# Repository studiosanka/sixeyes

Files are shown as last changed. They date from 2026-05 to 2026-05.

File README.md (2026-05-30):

# SixEyes - 6-DOF Robotic Arm with ROS2 Integration

An open-source, in-progress robotics platform for a 6-degree-of-freedom arm, spanning ESP32 firmware, ROS2 integration, teleoperation tooling, and hardware bring-up.

NodeMesh-specific firmware and IC-design work has moved to a dedicated repository: [https://github.com/SixEyes-Open-Source/nodemesh](https://github.com/SixEyes-Open-Source/nodemesh).

## Scope Clarity (Read This First)

SixEyes is the standard robotic-arm package.

- Standard path in this repository: arm hardware + follower/leader firmware + laptop/ROS2-assisted operation.
- Optional path in NodeMesh repository: 4-MCU edge firmware system with camera nodes and ESP-NOW.

Important default policy for this repository:
- SD card reader hardware may be present as a compatibility option, but it is not part of the default sixeyes runtime flow.
- ESP32-CAM perception nodes are not part of the standard sixeyes package.

Canonical split across all repos:
- [Project Scope And Repo Map](docs/PROJECT_SCOPE_AND_REPO_MAP.md)

## Quick Links

- 📘 **Getting Started**: Read [Complete Documentation Index](docs/README.md#quick-start)
- 🧠 **NodeMesh Repository**: [SixEyes-Open-Source/nodemesh](https://github.com/SixEyes-Open-Source/nodemesh)
- 🚀 **Deploy Firmware**: [Flashing & Deployment Guide](docs/deployment/FLASHING_AND_DEPLOYMENT.md)
- 🔌 **Build Hardware**: [Wiring & Assembly Guide](docs/hardware/WIRING_AND_ASSEMBLY.md)
- 🧩 **Pinout Matrix**: [Dual-Controller Pinout & Wiring Matrix](docs/hardware/DUAL_CONTROLLER_PINOUT_MATRIX.md)
-  **System Architecture**: [Visual Architecture Guide](docs/firmware/VISUAL_ARCHITECTURE_GUIDE.md)
- 🎮 **Teleoperation Architecture**: [Dual-Mode Firmware Plan](docs/firmware/TELEOPERATION_MODE_ARCHITECTURE.md)
- ✅ **Validate Hardware**: [Hardware Validation Procedures](docs/hardware/HARDWARE_VALIDATION.md)
- 🛠️ **Run Tests**: [Testing & Validation Guide](docs/testing/TESTING_AND_VALIDATION_GUIDE.md)

## Project Overview

### System Architecture

```
┌─────────────────────────────────┐
│  ROS2 Safety Node (Laptop)      │
│  • Heartbeat control (50 Hz)    │
│  • Motion planning              │
│  • Emergency stop logic         │
└──────────────┬──────────────────┘
               │ USB-CDC (ASCII)
┌──────────────▼──────────────────┐
│  ESP32-S3 Follower (Embedded)   │
│  • 500 Hz control loop          │
│  • Motor drivers (TMC2209)      │
│  • Servo control (LEDC PWM)     │
│  • Safety monitoring            │
└──────────────┬──────────────────┘
               │ Power + Control
┌──────────────▼──────────────────┐
│  Hardware (SixEyes Robot)       │
│  • 4× NEMA23 steppers (24V)     │
│  • 3× MG996R servos (6.6V rail) │
│  • USB-CDC telemetry            │
└─────────────────────────────────┘
```

### Key Features

✅ **Safety-Critical**: Dual heartbeat monitoring with <2.5 ms motor disable latency  
✅ **Real-Time Control**: 500 Hz FreeRTOS deterministic control loop  
✅ **Extensible**: JSON message protocol for future expansion  
🚧 **In Active Development**: Architecture and workflows are evolving as teleoperation and ROS2 integration mature  
✅ **Well-Tested**: Unit tests + hardware validation procedures  
✅ **CI/CD Ready**: GitHub Actions for automated builds and releases  

### Firmware Operation Modes

| Mode | Purpose | Data Path | Status |
|---|---|---|---|
| **VLA Inference** | Execute AI-planned tasks from laptop/ROS2 | Laptop ROS2 → Follower ESP32 | ✅ Active |
| **Teleoperation** | Stream human-driven leader joint states for mirroring/data collection | Leader ESP32 → Laptop → Follower | ✅ Fully wired (hardware pending) |

Current implementation includes `leader_esp32` JOINT_STATE streaming at 100 Hz, laptop bridge forwarding, teleoperation command handling on follower, and operator utilities for safe command sequencing.

### Choose Your Mode First (Important)

Before building/flashing, choose one workflow and set follower mode accordingly:

1. **VLA Inference workflow**
    - Set in `firmware/follower_esp32/platformio.ini`:
       ```ini
       -DOPERATION_MODE=1
       ```
    - Flash only `follower_esp32`
    - Run ROS2 safety + command nodes from laptop

2. **Teleoperation workflow**
    - Set in `firmware/follower_esp32/platformio.ini`:
       ```ini
       -DOPERATION_MODE=2
       ```
    - Flash both `leader_esp32` and `follower_esp32`
    - Run laptop bridge (`tools/teleoperation_bridge.py`)

## Repository Structure

```
firmware/
├── follower_esp32/              ← Main firmware
│   ├── src/
│   │   ├── main.cpp             (entry point)
│   │   ├── modules/
│   │   │   ├── motor_control/   (500 Hz PID control loop)
│   │   │   ├── servo_control/   (LEDC PWM servo manager)
│   │   │   ├── safety/          (heartbeat, fault manager, safety task)
│   │   │   ├── comms/           (USB-CDC, JSON parser, message router)
│   │   │   ├── modes/           (vla_inference, teleoperation handlers)
│   │   │   ├── drivers/         (TMC2209, LEDC)
│   │   │   └── hal/             (GPIO, timekeeping)
│   │   └── config/              (board_config.h, mode_config.h)
│   ├── test/                    (unit tests & mocks)
│   ├── platformio.ini           (build config)
│   └── lib_deps                 (dependencies)
└── leader_esp32/                (teleoperation joint-state streamer, 100 Hz)

ros2_ws/                         ← ROS2 workspace (runs on laptop)
├── src/
│   ├── safety_node/             ✅ Monitors firmware status, publishes /sixeyes/is_safe
│   ├── vla_inference_node/      🚧 VLA inference stub (in development)
│   ├── camera_node/             ✅ OpenCV camera → /camera/image_raw
│   ├── joint_state_node/        ✅ Bridges /sixeyes/joint_states → /joint_states (rad)
│   └── usb_bridge_node/         ✅ Owns serial port; heartbeat TX, telemetry RX, command TX

simulation/                      ← Gazebo simulation
├── models/
└── launch/

hardware_assets/                 ← Mechanical + PCB production files
├── 3d_print_stl/                (STL files for printed parts)
└── pcb_schematic_gerber/        (schematics + Gerbers)

SixEyes Follower PCB/            ← KiCad PCB project (follower controller board)
├── SixEyes Follower PCB.kicad_pcb
├── SixEyes Follower PCB.kicad_sch
├── SixEyes Follower PCB.kicad_pro
├── SixEyes_Custom.pretty/       (custom footprint library)
└── design_inputs/               (netlists, footprint maps)

docs/                            ← Documentation ⭐ START HERE
├── README.md                    (doc navigation)
├── firmware/                    (implementation guides)
├── hardware/                    (wiring & assembly)
├── deployment/                  (flashing guide)
├── testing/                     (validation procedures)
├── protocols/                   (message specs)
├── ros2/                        (ROS2 integration)
├── ops/                         (CI/CD pipeline)
└── references/                  (datasheets, etc)

.github/workflows/               ← CI/CD pipelines
├── platformio-build.yml
├── code-quality.yml
└── release.yml

CONTRIBUTING.md                  (contribution guidelines)
LICENSE                          (project license)
README.md                        (this file)
```

## Getting Started (5 minutes)

### Quick Mode Setup

```bash
# Follower mode switch (edit before build)
cd firmware/follower_esp32
# platformio.ini -> -DOPERATION_MODE=1  (VLA)
# platformio.ini -> -DOPERATION_MODE=2  (Teleoperation)
```

### For Firmware Developers

1. **Clone the repository**:
   ```bash
   git clone https://github.com/SixEyes-Open-Source/sixeyes.git
   ```
   All code is at the repository root — `firmware/`, `ros2_ws/`, `tools/` etc. are top-level folders.

2. **Install PlatformIO**:
   ```bash
   pip install platformio
   cd firmware/follower_esp32
   ```

3. **Build firmware**:
   ```bash
   pio run
   ```

4. **Flash to ESP32**:
   ```bash
   pio run -t upload
   ```

5. **Monitor output**:
   ```bash
   pio device monitor
   ```

⏭️ **Next**: Read [Flashing & Deployment Guide](docs/deployment/FLASHING_AND_DEPLOYMENT.md)

### For Teleoperation Mode (Phase 2)

1. **Build leader streamer firmware**:
   ```bash
   cd firmware/leader_esp32
   pio run
   ```

2. **Build follower in teleoperation mode**:
   ```bash
   cd ../follower_esp32
   # Ensure platformio.ini has: -DOPERATION_MODE=2
   pio run
   ```

3. **Flash leader ESP32**:
   ```bash
   cd ../leader_esp32
   pio run -t upload
   ```

4. **Flash follower ESP32**:
   ```bash
   cd ../follower_esp32
   pio run -t upload
   ```

5. **Monitor JOINT_STATE output (100 Hz)**:
   ```bash
   cd ../leader_esp32
   pio device monitor
   ```

6. **Capture leader pot home pose as zero (in leader monitor)**:
   ```text
   HOME_ZERO
   ```
   Or JSON form:
   ```json
   {"cmd":"CAPTURE_ZERO"}
   ```
   Expected monitor response:
   ```text
   [CAL] Leader pot zero captured from current pose
   ```

7. **Run laptop bridge with dataset capture**:
   ```bash
   cd tools
   python teleoperation_bridge.py --leader-port COM5 --follower-port COM6 --log-file logs/teleop_session.jsonl
   ```

8. **Validate captured JSONL against schema**:
   ```bash
   cd tools
   python validate_teleop_log.py --input logs/teleop_session.jsonl
   ```

9. **Run operator workflow helper (optional, follower commands + heartbeat)**:
   ```bash
   cd tools
   python operator_control.py --port COM6 teleop-ready
   python operator_control.py --port COM6 home
   python operator_control.py --port COM6 stallguard-home
   ```

⏭️ **Next**: Read [Teleoperation Mode Architecture](docs/firmware/TELEOPERATION_MODE_ARCHITECTURE.md)

### For Hardware Assembly

1. **Gather components** from [Parts List](docs/hardware/WIRING_AND_ASSEMBLY.md#parts-list)
2. **Follow wiring diagram** in [Wiring Guide](docs/hardware/WIRING_AND_ASSEMBLY.md)
3. **Run hardware validation** tests from [Hardware Validation](docs/hardware/HARDWARE_VALIDATION.md)

⏭️ **Next**: Read [WIRING_AND_ASSEMBLY.md](docs/hardware/WIRING_AND_ASSEMBLY.md)

### For ROS2 Integration

1. **Set up ROS2 workspace**:
   ```bash
   cd ros2_ws
   colcon build
   source install/setup.bash
   ```

2. **Run all nodes** with a single launch command:
   ```bash
   # Teleoperation mode (4 nodes)
   ros2 launch sixeyes_bringup teleop.launch.py port:=/dev/ttyACM0

   # VLA inference mode (5 nodes, includes vla_inference_node stub)
   ros2 launch sixeyes_bringup vla.launch.py port:=/dev/ttyACM0
   ```

3. **Monitor firmware status**:
   ```bash
   ros2 topic echo /sixeyes/firmware_status
   ros2 topic echo /sixeyes/is_safe
   ```

⏭️ **Next**: Read [ROS2 Integration Guide](docs/ros2/ROS2_HEARTBEAT_INTEGRATION.md)

## Technical Specifications

| Feature | Specification |
|---|---|
| **Controller** | ESP32-S3 (240 MHz dual-core, 320 KB RAM) |
| **Control Loop** | 500 Hz FreeRTOS deterministic timing |
| **Steppers** | 4× NEMA23 (24V, 2.8A nominal) via TMC2209 |
| **Servos** | 3× MG996R (6.6V rail, 0.17 sec/60°) |
| **Communication** | USB-CDC + heartbeat protocol (50+ Hz) |
| **Safety Timeout** | 500 ms heartbeat detection + <2.5 ms motor disable |
| **Memory Usage** | 6.1% RAM, 10% Flash |
| **Build Status** | Zero compiler warnings ✅ |

## Key Documentation Files

### 📚 Architecture & Design
- [Visual Architecture Guide](docs/firmware/VISUAL_ARCHITECTURE_GUIDE.md) - System diagrams, control flow, timing diagrams
- [Implementation Summary](docs/firmware/IMPLEMENTATION_SUMMARY.md) - Technical specifications, protocol details

### 🔧 Hardware & Deployment
- [Wiring & Assembly](docs/hardware/WIRING_AND_ASSEMBLY.md) - Complete pin mapping, parts list, assembly procedures
- [Hardware Validation](docs/hardware/HARDWARE_VALIDATION.md) - Testing & qualification procedures
- [Flashing & Deployment](docs/deployment/FLASHING_AND_DEPLOYMENT.md) - Firmware build, flash, troubleshooting

### 🧪 Testing & Quality
- [Testing & Validation Guide](docs/testing/TESTING_AND_VALIDATION_GUIDE.md) - Unit tests, test framework, coverage
- [CI/CD Pipeline](docs/ops/CI_CD_PIPELINE.md) - GitHub Actions, automated builds, release process

### 🚀 Communication & ROS2
- [JSON Message Protocol](docs/protocols/JSON_MESSAGE_PROTOCOL.md) - Message specifications, command reference
- [ROS2 Heartbeat Integration](docs/ros2/ROS2_HEARTBEAT_INTEGRATION.md) - Safety protocol, integration details
- [ROS2 Quickstart](docs/ros2/ROS2_HEARTBEAT_QUICKSTART.md) - Step-by-step testing guide

### 📋 References
- [Datasheets & References](docs/references/) - TMC2209, hardware specs, technical references
- [Firmware System Datasheet](docs/references/FIRMWARE_SYSTEM_DATASHEET.md) - IC-style firmware system snapshot (interfaces, safety, limits, maturity)

## Communication Protocols

### ASCII Heartbeat (High-Priority Safety)

**ROS2 → ESP32** (≥50 Hz):
```
HB:0,<sequence>\n
```

**ESP32 → ROS2** (10 Hz):
```
SB:<fault>,<motors_enabled>,<ros2_alive>\n
```

### JSON Message Protocol (Extensible Commands)

```json
{
  "cmd": "MOTOR_TARGET",
  "seq": 1,
  "targets": [0.0, 45.0, 90.0, 135.0]
}
```

See [JSON Message Protocol](docs/protocols/JSON_MESSAGE_PROTOCOL.md) for full specification.

## Safety & Reliability

### Motor Disable Guarantees

- **Automatic Disable**: If ROS2 heartbeat lost for >500 ms
- **Latency**: Motor disable within 1 control loop cycle (~2.5 ms)
- **Dual Monitoring**: Both ROS2 and internal heartbeat must be healthy
- **Non-blocking**: All safety checks run asynchronously to preserve control loop timing

### Testing & Validation

✅ 17 unit tests (all passing)  
✅ 15 hardware validation procedures  
✅ CI/CD automated builds with memory constraints  
⚠️ Some non-blocking ArduinoJson deprecation warnings remain  
✅ Build-ready code quality (leader + follower compile successfully)  

## Development Workflow

### Building Locally

```bash
cd firmware/follower_esp32
pio run              # Build
pio run -t upload    # Flash
pio device monitor   # Monitor
```

### Running Unit Tests

```bash
cd firmware/follower_esp32
pio test             # Run all tests
```

### Contributing

See [CONTRIBUTING.md](CONTRIBUTING.md) for:
- Code style guidelines
- Pull request process
- Commit message conventions
- Testing requirements

## Troubleshooting

### Compilation Issues
👉 See [Build Troubleshooting](docs/deployment/FLASHING_AND_DEPLOYMENT.md#troubleshooting)

### Hardware Not Responding
👉 See [Hardware Validation](docs/hardware/HARDWARE_VALIDATION.md#troubleshooting)

### ROS2 Communication Problems
👉 See [ROS2 Quickstart - Troubleshooting](docs/ros2/ROS2_HEARTBEAT_QUICKSTART.md#troubleshooting)

## Project Status

| Component | Status | Notes |
|---|---|---|
| Firmware Core (VLA) | ✅ Stable | Follower control loop + safety heartbeat |
| Firmware Core (Teleop) | ✅ Active | Leader stream + bridge + follower telemetry + schema-validated logging |
| Documentation | ✅ Active | Dual-mode docs updated; ongoing refinements |
| Unit Tests | 🟡 Partial | Existing tests pass; teleop path tests still needed |
| CI/CD Pipeline | ✅ Complete | 3 GitHub Actions workflows |
| Hardware Validation | ✅ Available | Baseline + teleoperation checks documented |
| ROS2 Integration | 🟡 Partial | Heartbeat path done; teleop ROS nodes need expansion |
| Production Readiness | 🚧 In Progress | Core safety + control are advancing; end-to-end teleop and ROS2 workflows are still being completed |

## Current TODO (High Priority)

1. Add automated integration test for `leader_esp32` → bridge → `follower_esp32`
2. Expand ROS2 workspace teleoperation nodes (`joint_state_node`, `usb_bridge_node`) for end-to-end runtime
3. Finalize hardware bring-up checklist for dual-controller (leader + follower) setups

## Performance Metrics

```
Control Loop Frequency:      400 Hz ✓
Motor Disable Latency:       < 2.5 ms ✓
Firmware Size:               335 KB ✓
RAM Usage:                   6.1% ✓
Flash Usage:                 10% ✓
Compiler Warnings:           0 ✓
Unit Test Coverage:          17 tests passing ✓
```

## License

This project is licensed under the [LICENSE](LICENSE) file.

## Contact & Support

For issues, questions, or contributions:
- 📧 Email: sixeyesopensource@gmail.com
- 🐛 Issues: https://github.com/SixEyes-Open-Source/sixeyes/issues
- 💬 Discussions: https://github.com/SixEyes-Open-Source/sixeyes/discussions

---

**Last Updated**: March 2026  
**Latest Version**: Check [Releases](https://github.com/SixEyes-Open-Source/sixeyes/releases)

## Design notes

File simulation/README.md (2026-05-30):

# Simulation

Place simulators and models here. Simulation-first development is required. Use this folder for Gazebo/ignition or pybullet scenes that mimic the real robot and its power/safety constraints.

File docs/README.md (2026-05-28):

# SixEyes Documentation Index

Navigation guide for SixEyes firmware, ROS2, teleoperation, and hardware documentation.

NodeMesh-specific materials now live in a separate repository: [https://github.com/SixEyes-Open-Source/nodemesh](https://github.com/SixEyes-Open-Source/nodemesh).

## Scope Boundary (Critical)

- This docs tree is for standard sixeyes hardware and firmware workflows.
- NodeMesh is optional and maintained in a separate repository.
- If you are doing the default build, you do not need NodeMesh docs.

See authoritative boundaries here:
- [Project Scope And Repo Map](PROJECT_SCOPE_AND_REPO_MAP.md)

## Minimal Start Path (3 Docs Only)

If you feel overwhelmed, start with only these:

1. [Wiring & Assembly](hardware/WIRING_AND_ASSEMBLY.md)
2. [Flashing & Deployment](deployment/FLASHING_AND_DEPLOYMENT.md)
3. [Hardware Validation](hardware/HARDWARE_VALIDATION.md)

Then expand to other docs only as needed.

## Quick Start

👉 **New to SixEyes?** Start here based on your role:

### 🧑‍💻 Firmware Developers
1. Read: [Implementation Summary](firmware/IMPLEMENTATION_SUMMARY.md) (5 min)
2. Read: [Visual Architecture Guide](firmware/VISUAL_ARCHITECTURE_GUIDE.md) (10 min)
3. Read: [Teleoperation Mode Architecture](firmware/TELEOPERATION_MODE_ARCHITECTURE.md) (dual-mode design)
4. Follow: [Flashing & Deployment](deployment/FLASHING_AND_DEPLOYMENT.md) to build firmware
5. Run: [Unit Tests](testing/TESTING_AND_VALIDATION_GUIDE.md) to verify code

### 🎮 Teleoperation Developers
1. Read: [Teleoperation Mode Architecture](firmware/TELEOPERATION_MODE_ARCHITECTURE.md)
2. Reference: [JSON Message Protocol](protocols/JSON_MESSAGE_PROTOCOL.md#teleoperation-streaming-messages-phase-2)
3. Build: `sixeyes/firmware/leader_esp32` (joint-state streamer)
4. Run bridge: `python sixeyes/tools/teleoperation_bridge.py --leader-port COM5 --follower-port COM6`
5. Validate: `JOINT_STATE` forwarding + optional JSONL logging
6. Optional: run `python sixeyes/tools/operator_control.py --port COM6 teleop-ready` for follower-side safety/enable command flow

### 🔧 Hardware Integrators
1. Gather: [Parts List](hardware/WIRING_AND_ASSEMBLY.md#parts-list)
2. Follow: [Wiring & Assembly](hardware/WIRING_AND_ASSEMBLY.md) step-by-step
3. Run: [Hardware Validation Tests](hardware/HARDWARE_VALIDATION.md) to verify setup
4. Deploy: [Flashing Guide](deployment/FLASHING_AND_DEPLOYMENT.md) to install firmware

### 🤖 ROS2 Engineers
1. Read: [ROS2 Heartbeat Integration](ros2/ROS2_HEARTBEAT_INTEGRATION.md) (understand protocol)
2. Follow: [ROS2 Quickstart](ros2/ROS2_HEARTBEAT_QUICKSTART.md) for testing
3. Reference: [JSON Message Protocol](protocols/JSON_MESSAGE_PROTOCOL.md) for commands
4. Check: [CI/CD Pipeline](ops/CI_CD_PIPELINE.md) for build automation

### 🚀 DevOps / Release Engineers
1. Read: [CI/CD Pipeline Documentation](ops/CI_CD_PIPELINE.md)
2. Review: [Flashing & Deployment](deployment/FLASHING_AND_DEPLOYMENT.md#release--version-management)
3. Check: [GitHub Workflows](.github/workflows/) for automation details

---

## Documentation by Category

### 📘 Firmware Architecture & Design

#### [Implementation Summary](firmware/IMPLEMENTATION_SUMMARY.md)
- **Contents**: ROS2 heartbeat protocol, module specifications, compilation results
- **Best For**: Understanding core firmware architecture, protocol details
- **Read Time**: 20 minutes
- **Key Sections**:
  - Bidirectional heartbeat protocol (HB: and SB: packets)
  - Four firmware modules (HeartbeatReceiver, SafetyBridge, HeartbeatTransmitter, SafetyNodeBridge)
  - SafetyTask integration with ROS2 hooks
  - Performance metrics (6.1% RAM, 10% Flash)

#### [Visual Architecture Guide](firmware/VISUAL_ARCHITECTURE_GUIDE.md)
- **Contents**: System diagrams, control flow, timing analysis, pin mapping
- **Best For**: Visual learners, understanding data flow, timing guarantees
- **Read Time**: 15 minutes
- **Key Sections**:
  - High-level system architecture diagram
  - 400 Hz control loop timeline (2.5 ms per cycle breakdown)
  - Module dependency graph
  - Hardware pin mapping and configuration
  - Signal flow diagrams

#### [Teleoperation Mode Architecture](firmware/TELEOPERATION_MODE_ARCHITECTURE.md)
- **Contents**: Dual-mode firmware plan, teleoperation protocol, module roadmap
- **Best For**: Implementing leader-follower mirroring and data-collection flow
- **Read Time**: 15 minutes
- **Key Sections**:
  - VLA Inference vs Teleoperation mode comparison
  - `JOINT_STATE` and `TELEMETRY_STATE` data-flow design
  - Phase-based implementation plan (Phase 1 → Phase 3)

---

### 🔌 Hardware & Assembly

#### [Wiring & Assembly](hardware/WIRING_AND_ASSEMBLY.md)
- **Contents**: Parts list, pinout reference, power distribution, motor/servo wiring
- **Best For**: Physical hardware assembly, electrical integration
- **Read Time**: 30 minutes
- **Key Sections**:
  - Complete parts list with part numbers
  - ESP32-S3 pin assignments (all pins documented)
  - TMC2209 stepper driver wiring
  - Servo motor connections (LEDC PWM)
  - Power distribution strategy (star grounding)
  - Grounding and noise management

#### [Dual-Controller Pinout & Wiring Matrix](hardware/DUAL_CONTROLLER_PINOUT_MATRIX.md)
- **Contents**: Consolidated pin map for leader ESP32-C6 SuperMini and follower ESP32-S3, 4× TMC2209 channels, servos, UART links, and power rails
- **Best For**: Fast verification of inter-board wiring and GPIO assignments against Technical Reference 2
- **Read Time**: 8 minutes
- **Key Sections**:
  - Leader ADC and UART pin mapping
  - Follower TMC2209 + servo pin mapping
  - Inter-board UART cross-link table
  - Power rail distribution and grounding rules

#### [Hardware Validation](hardware/HARDWARE_VALIDATION.md)
- **Contents**: Testing procedures, validation checklists, troubleshooting
- **Best For**: Verifying hardware is correctly assembled
- **Read Time**: 20 minutes (execution time ~2 hours for full validation)
- **Key Sections**:
  - Pre-testing checklists (power, connections, firmware)
  - Unit-level tests (power-on, GPIO blink, UART loopback)
  - Integration tests (motor enable/disable, heartbeat timeout, servo response)
  - System-level tests (load testing, stress testing)
  - Failure mode testing and recovery

---

### 🚀 Firmware Deployment

#### [Flashing & Deployment](deployment/FLASHING_AND_DEPLOYMENT.md)
- **Contents**: Build instructions, flashing methods, diagnostics, troubleshooting
- **Best For**: Compiling and installing firmware on ESP32
- **Read Time**: 25 minutes (execution time ~10 minutes per flash)
- **Key Sections**:
  - Pre-deployment checklist (tools, hardware prep, prerequisites)
  - Firmware build with PlatformIO (CLI and VS Code)
  - Multiple flashing methods (USB in DFU mode, UART serial)
  - Serial monitor diagnostics and startup verification
  - Troubleshooting common build and flash errors
  - Release and version management

---

### 🧪 Testing & Quality Assurance

#### [Testing & Validation Guide](testing/TESTING_AND_VALIDATION_GUIDE.md)
- **Contents**: Unit test framework, running tests, coverage, simulation
- **Best For**: Developers writing and running unit tests
- **Read Time**: 20 minutes
- **Key Sections**:
  - Unit test framework architecture (mock hardware objects)
  - MockSerial, MockGPIO, MockTimer, MockFreeRTOS
  - Running tests on desktop (no ESP32 required)
  - Test coverage analysis (heartbeat parsing, safety logic, motor control)
  - Simulation harness for non-blocking operations
  - CI/CD integration with GitHub Actions

---

### 🛠️ Communication Protocols

#### [JSON Message Protocol](protocols/JSON_MESSAGE_PROTOCOL.md)
- **Contents**: Message format, command types, response types, error handling
- **Best For**: Building ROS2 nodes or custom applications
- **Read Time**: 25 minutes
- **Key Sections**:
  - Protocol overview (extensible, non-blocking, type-safe)
  - Message format with common fields (cmd, seq, ts)
  - Command and response message reference (implemented + planned)
  - Examples for each message type
  - Error handling and edge cases
  - Integration examples with Python/C++

---

### 🤖 ROS2 Integration

#### [ROS2 Heartbeat Integration](ros2/ROS2_HEARTBEAT_INTEGRATION.md)
- **Contents**: Heartbeat protocol, module breakdown, architecture, integration details
- **Best For**: Understanding heart beat safety mechanism
- **Read Time**: 20 minutes
- **Key Sections**:
  - Bidirectional heartbeat protocol (HB and SB packets)
  - Safety guarantees (dual heartbeat monitoring, <2.5 ms disable latency)
  - Module architecture (HeartbeatReceiver, Monitor, Transmitter)
  - Integration with SafetyTask and motor control
  - Timing and latency analysis

#### [ROS2 Quickstart Guide](ros2/ROS2_HEARTBEAT_QUICKSTART.md)
- **Contents**: Step-by-step testing, hardware setup, troubleshooting
- **Best For**: Quick hands-on testing of ROS2 integration
- **Read Time**: 15 minutes (testing ~30 minutes)
- **Key Sections**:
  - Quick verification test (2 minutes)
  - Full integration test (15 minutes)
  - Python node examples with diagnostics
  - Stress testing and failure injection
  - Common issues and solutions

---

### ⚙️ Operations & CI/CD

#### [CI/CD Pipeline](ops/CI_CD_PIPELINE.md)
- **Contents**: GitHub Actions workflows, build configuration, testing automation
- **Best For**: DevOps engineers, release automation
- **Read Time**: 20 minutes
- **Key Sections**:
  - Pipeline architecture overview
  - Build workflow (PlatformIO compilation, memory constraints)
  - Code quality workflow (static analysis, linting)
  - Release workflow (versioning, artifact generation)
  - Configuration customization
  - Troubleshooting build failures

---

### 📚 References & Resources

#### [References Directory](references/)
- **Contents**: Datasheets, technical specifications, hardware manuals
- **Best For**: Looking up chip specifications, pinouts, electrical specs
- **Files**:
  - `FIRMWARE_SYSTEM_DATASHEET.md` - Firmware-level system datasheet (interfaces, limits, safety behavior, maturity)
  - `SixEyes Technical Reference.txt` - Hardware technical specifications

---

## Documentation Map by Task

### Task: "I need to build the hardware"
1. Start: [Wiring & Assembly](hardware/WIRING_AND_ASSEMBLY.md)
2. Verify: [Hardware Validation](hardware/HARDWARE_VALIDATION.md)
3. Install: [Flashing & Deployment](deployment/FLASHING_AND_DEPLOYMENT.md)

### Task: "I need to understand how it works"
1. Start: [Implementation Summary](firmware/IMPLEMENTATION_SUMMARY.md)
2. Visualize: [Visual Architecture Guide](firmware/VISUAL_ARCHITECTURE_GUIDE.md)
3. Deep dive: [JSON Message Protocol](protocols/JSON_MESSAGE_PROTOCOL.md)

### Task: "I need to set up ROS2"
1. Start: [ROS2 Heartbeat Integration](ros2/ROS2_HEARTBEAT_INTEGRATION.md)
2. Test: [ROS2 Quickstart](ros2/ROS2_HEARTBEAT_QUICKSTART.md)
3. Command: [JSON Message Protocol](protocols/JSON_MESSAGE_PROTOCOL.md)

### Task: "I need to run the tests"
1. Start: [Testing & Validation Guide](testing/TESTING_AND_VALIDATION_GUIDE.md)
2. Hardware: [Hardware Validation](hardware/HARDWARE_VALIDATION.md)
3. CI/CD: [CI/CD Pipeline](ops/CI_CD_PIPELINE.md)

### Task: "I need to deploy a new version"
1. Start: [Flashing & Deployment](deployment/FLASHING_AND_DEPLOYMENT.md)
2. CI/CD: [CI/CD Pipeline](ops/CI_CD_PIPELINE.md)
3. Release: [Flashing Guide - Release Section](deployment/FLASHING_AND_DEPLOYMENT.md#release--version-management)

### Task: "Something's broken, how do I fix it?"
1. Check: [Flashing & Deployment - Troubleshooting](deployment/FLASHING_AND_DEPLOYMENT.md#troubleshooting)
2. Or: [Hardware Validation - Troubleshooting](hardware/HARDWARE_VALIDATION.md#troubleshooting)
3. Or: [ROS2 Quickstart - Troubleshooting](ros2/ROS2_HEARTBEAT_QUICKSTART.md#troubleshooting)

---

## Document Statistics

| Category | Document | Pages | Read Time |
|---|---|---|---|
| Firmware | Implementation Summary | 20 | 20 min |
| Firmware | Visual Architecture | 35 | 15 min |
| Hardware | Wiring & Assembly | 40 | 30 min |
| Hardware | Hardware Validation | 22 | 20 min |
| Deployment | Flashing & Deployment | 42 | 25 min |
| Testing | Testing & Validation | 24 | 20 min |
| Protocols | JSON Message Protocol | 34 | 25 min |
| ROS2 | Heartbeat Integration | 15 | 20 min |
| ROS2 | Quickstart Guide | 20 | 15 min |
| Ops | CI/CD Pipeline | 24 | 20 min |
| **Total** | **10 Documents** | **276** | **190 min** |

---

## Navigation Tips

### By File Size (Least to Most Reading)
1. ⚡ Quick (5-10 min): ROS2 Quickstart, CI/CD Pipeline intro
2. 📖 Medium (15-20 min): Implementation Summary, Hardware Validation
3. 📚 Deep Dive (25-30 min): Wiring & Assembly, Flashing & Deployment, JSON Protocol

### By Priority
1. 🔴 **Critical** (must read): Implementation Summary, Wiring & Assembly, Flashing & Deployment
2. 🟡 **Important** (should read): Hardware Validation, ROS2 Integration, Visual Architecture
3. 🟢 **Reference** (look up as needed): JSON Protocol, CI/CD Pipeline, Testing Guide

### By Audience
- **Hardware Teams**: Wiring & Assembly → Hardware Validation → Flashing
- **Firmware Teams**: Implementation Summary → Visual Architecture → Testing & Validation
- **ROS2 Teams**: ROS2 Integration → JSON Protocol → ROS2 Quickstart
- **DevOps**: CI/CD Pipeline → Flashing (Release section)

---

## Cross-Reference Guide

### Protocol Details
- **Heartbeat packets**: [Implementation Summary](firmware/IMPLEMENTATION_SUMMARY.md#protocol-specification)
- **JSON messages**: [JSON Message Protocol](protocols/JSON_MESSAGE_PROTOCOL.md)
- **Timing specs**: [Visual Architecture Guide](firmware/VISUAL_ARCHITECTURE_GUIDE.md#400-hz-control-loop-timing)
- **Safety guarantees**: [ROS2 Integration](ros2/ROS2_HEARTBEAT_INTEGRATION.md#safety-guarantees)

### Hardware Details
- **Pin assignments**: [Visual Architecture Guide](firmware/VISUAL_ARCHITECTURE_GUIDE.md#hardware-pin-mapping)
- **Wiring diagrams**: [Wiring & Assembly](hardware/WIRING_AND_ASSEMBLY.md#pinout-reference)
- **Motor specs**: [Wiring & Assembly](hardware/WIRING_AND_ASSEMBLY.md#parts-list)
- **Power distribution**: [Wiring & Assembly](hardware/WIRING_AND_ASSEMBLY.md#power-distribution)

### Testing & Validation
- **Unit tests**: [Testing Guide](testing/TESTING_AND_VALIDATION_GUIDE.md#unit-test-framework)
- **Hardware tests**: [Hardware Validation](hardware/HARDWARE_VALIDATION.md)
- **Integration tests**: [ROS2 Quickstart](ros2/ROS2_HEARTBEAT_QUICKSTART.md)
- **CI/CD tests**: [CI/CD Pipeline](ops/CI_CD_PIPELINE.md#build-workflow)

### Build & Deployment
- **Compilation**: [Flashing & Deployment](deployment/FLASHING_AND_DEPLOYMENT.md#firmware-build--compilation)
- **Flashing**: [Flashing & Deployment](deployment/FLASHING_AND_DEPLOYMENT.md#flashing-methods)
- **Troubleshooting**: [Flashing & Deployment](deployment/FLASHING_AND_DEPLOYMENT.md#troubleshooting)
- **Release process**: [CI/CD Pipeline](ops/CI_CD_PIPELINE.md#release-workflow)

---

## Getting Help

### Common Questions

**Q: Where do I start?**
A: See the Quick Start section above for your role.

**Q: How do I understand the system architecture?**
A: Read [Implementation Summary](firmware/IMPLEMENTATION_SUMMARY.md) first, then [Visual Architecture Guide](firmware/VISUAL_ARCHITECTURE_GUIDE.md).

**Q: How do I wire the hardware?**
A: Follow [Wiring & Assembly](hardware/WIRING_AND_ASSEMBLY.md) step-by-step, using the pin maps in [Visual Architecture Guide](firmware/VISUAL_ARCHITECTURE_GUIDE.md).

**Q: How do I test my hardware?**
A: Run the procedures in [Hardware Validation](hardware/HARDWARE_VALIDATION.md).

**Q: How do I flash the firmware?**
A: Follow [Flashing & Deployment](deployment/FLASHING_AND_DEPLOYMENT.md).

**Q: How do I integrate with ROS2?**
A: Read [ROS2 Heartbeat Integration](ros2/ROS2_HEARTBEAT_INTEGRATION.md), then follow [ROS2 Quickstart](ros2/ROS2_HEARTBEAT_QUICKSTART.md).

**Q: How do I run tests?**
A: See [Testing & Validation Guide](testing/TESTING_AND_VALIDATION_GUIDE.md).

**Q: How do I set up CI/CD?**
A: See [CI/CD Pipeline](ops/CI_CD_PIPELINE.md).

---

## Version History

| Date | Version | Changes |
|---|---|---|
| Feb 2026 | 2.0 | Documentation reorganized into docs/ directory structure |
| Jan 2026 | 1.0 | Initial documentation release |

---

**Last Updated**: February 2026  
**Documentation Version**: 2.0  
**Status**: 🚧 Active and evolving with ongoing teleoperation + ROS2 updates

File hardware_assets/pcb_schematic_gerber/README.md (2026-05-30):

# PCB Schematic and Gerber Files

Place PCB design artifacts here.

Recommended structure:
- `schematic/` (PDF exports, source files)
- `gerber/` (manufacturing Gerber + drill files)
- `bom/` (Bill of Materials)
- `assembly/` (pick-and-place, fab notes)

Recommended naming format:
`<board_name>_v<major>.<minor>_<artifact>`

Examples:
- `follower_mainboard_v1.0_schematic.pdf`
- `follower_mainboard_v1.0_gerber.zip`

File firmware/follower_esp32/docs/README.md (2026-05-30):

# follower_esp32

Firmware running on `ESP32-S3-WROOM-1` responsible for deterministic control and safety according to the Technical Reference.

Key modules:
- motor_control
- drivers/tmc2209
- servo_control
- safety/heartbeat_monitor
- comms/uart_leader
- comms/usb_cdc (telemetry)

Motors are disabled by default on boot. See `modules/config/board_config.h`.

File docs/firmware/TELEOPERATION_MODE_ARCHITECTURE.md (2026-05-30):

# SixEyes Teleoperation Mode - Firmware Architecture

**Status**: Architecture + implementation reference for teleoperation firmware mode (Leader-Follower-Laptop)  
**Current scope**: Dual-mode firmware fully wired — compile-time mode selection (`OPERATION_MODE`), JOINT_STATE parsing via UartJsonParser callbacks, TELEMETRY_STATE streaming, 4 of 5 ROS2 nodes implemented  
**Next phase**: Hardware bring-up on test bench; ROS2 launch file; vla_inference_node implementation

---

## Executive Summary

### Current Implementation (VLA Inference Mode)
```
Laptop (ROS2 VLA Node)
        ↓
    Heartbeat (ASCII)
    Commands (JSON)
        ↓
Follower ESP32
        ↓
Motor Control (PID)
```

### Teleoperation Mode (Current Direction)
```
Leader Arm (GPIO/Sensor/Potentiometers)
        ↓
Leader ESP32 (record human motions)
        ↓ USB-CDC
Laptop (Optional: logging, replay, analysis)
        ↓ USB-CDC + WiFi (wireless optional)
Follower ESP32 (replay recorded motions)
        ↓
Follower Arm (mirror motions)
```

---

## Architecture Overview

### Two-Mode Firmware Design

```
┌─────────────────────────────────────────────────────────┐
│          Follower ESP32 Firmware (Dual-Mode)            │
├─────────────────────────────────────────────────────────┤
│                                                           │
│  Configuration Layer                                     │
│  ├─ OPERATION_MODE setting (build-time)                 │
│  ├─ Either VLA_INFERENCE or TELEOPERATION               │
│  └─ Mode selected per firmware build                    │
│                                                           │
│  ┌─ VLA Inference Mode (Current) ──────────────────┐    │
│  │ ├─ Heartbeat RX (ASCII: HB:0,N)                │    │
│  │ ├─ Command RX (JSON: motor positions)          │    │
│  │ ├─ Status TX (SB: fault state)                 │    │
│  │ └─ Control Loop: Apply target positions        │    │
│  └──────────────────────────────────────────────────┘    │
│                                                           │
  ├─ Teleoperation Mode (✅ Implemented) ──────────────────────────╼    │
  │ ├─ JOINT_STATE RX (UartJsonParser callback)        │    │
  │ ├─ 6-joint → 4-motor + 3-servo mapping              │    │
  │ ├─ TELEMETRY_STATE TX (100 Hz feedback)            │    │
  │ └─ Control Loop: Mirror leader positions            │    │
  └──────────────────────────────────────────────────────╼    │
                                                           │
  Common Control Loop (500 Hz FreeRTOS)                  │
  ├─ UartJsonParser.update() (drain serial, dispatch)   │
  ├─ Safety Monitor (always active)                      │
  ├─ Motor Controller (PID for both modes)               │
  ├─ Servo Manager (same for both modes)                 │
  └─ TeleoperationHandler.update() (telemetry TX timer)  │
│                                                           │
└─────────────────────────────────────────────────────────┘
```

---

## Mode Comparison

| Feature | VLA Inference | Teleoperation |
|---|---|---|
| **Leader Hardware** | None (laptop planner) | Potentiometers/Encoders (sensors) |
| **Leader Firmware** | None | ESP32 (sensor reading) |
| **Primary Input** | ROS2 AI predictions | Leader joint positions |
| **Input Format** | JSON commands (absolute positions) | JSON joint states (leader telemetry) |
| **Input Frequency** | 10-50 Hz (varies) | 100 Hz (real-time mirroring) |
| **Latency Requirement** | Moderate (<100ms) | Strict (20-50ms for smooth mirroring) |
| **Primary Use** | Task execution | Data collection, real-time control |
| **Safety Timeout** | 500 ms heartbeat | 500 ms heartbeat (same constant: `SAFETY_HEARTBEAT_TIMEOUT_MS`) |
| **Position Mapping** | Direct (leader frame) | Scaled (may differ between arms) |

---

## Firmware Structure for Dual-Mode Design

### Option 1: Compile-Time Mode Selection (Recommended for Initial Phase)

```
follower_esp32/
├── platformio.ini
│   └── build_flag: -DOPERATION_MODE=VLA_INFERENCE or TELEOPERATION
│
├── src/
│   ├── main.cpp              (mode-agnostic initialization)
│   ├── config/
│   │   ├── config.h          (OPERATION_MODE constant)
│   │   └── mode_config.h     (mode-specific parameters)
│   │
│   ├── modules/
│   │   ├── safety/           (always active)
│   │   ├── motor_control/    (always active)
│   │   ├── servo_control/    (always active)
│   │   │
│   │   ├── vla_inference/    (VLA mode only)
│   │   │   ├── heartbeat_receiver.h/cpp
│   │   │   ├── json_command_parser.h/cpp
│   │   │   └── status_transmitter.h/cpp
│   │   │
│   │   └── teleoperation/    (Teleoperation mode only)
│   │       ├── joint_state_receiver.h/cpp
│   │       ├── telemetry_transmitter.h/cpp
│   │       ├── position_mapper.h/cpp
│   │       └── sync_monitor.h/cpp
│   │
│   └── comms/
│       ├── uart_handler.h/cpp     (mode-aware routing)
│       └── message_router.h/cpp   (directs to correct parser)
│
└── test/
    ├── mock_hardware.h
    ├── test_vla_mode.cpp       (VLA-specific tests)
    └── test_teleoperation_mode.cpp  (Teleoperation tests)q 
```

### Option 2: Runtime Mode Selection (More Flexible, Phase 2)

Modify config at runtime:
- Boot into default mode
- Allow config command: `{"cmd":"SET_MODE","mode":"TELEOPERATION"}`
- Requires state machine to handle mode transitions
- Slightly more complex but allows switching between modes without reflash

---

## Teleoperation Mode - Component Specification

### 1. Joint State Receiver Module

**Purpose**: Parse incoming leader joint positions and map to follower coordinates

**Input Format (JSON)**:
```json
{
  "cmd": "JOINT_STATE",
  "seq": 42,
  "ts": 1000500,
  "leader_joints": [0.0, 45.0, 90.0, 135.0, 90.0, 90.0],
  "valid_mask": [1, 1, 1, 1, 1, 1]
}
```

**Fields**:
- `leader_joints`: Array of 6 joint angles (degrees) or -1 for invalid
- `valid_mask`: Binary flags for each joint (1=valid, 0=invalid/disconnected)

**Key Methods**:
```cpp
class JointStateReceiver {
  bool parseJointStateMessage(const JsonDocument& doc);
  float* getLeaderJointAngles();        // Pointer to latest joint angles
  uint32_t getSequenceNumber() const;
  uint32_t getTimestamp() const;
  bool isJointValid(int joint_idx) const;
  uint32_t getTimeSinceLastMessage() const;  // For timeout detection
};
```

**Behavior**:
- Non-blocking parsing (same as VLA mode)
- Tracks sequence numbers for gap detection
- Stores previous command for interpolation if needed
- Validates joint angles (within hardware limits)

---

### 2. Position Mapper Module

**Purpose**: Convert leader joint angles to follower target positions

**Features**:
- **Identity mapping** (default): `follower_target = leader_angle`
- **Scaled mapping**: Scale by mechanical ratio 
- **Inverted mapping**: Mirror specific axes
- **Offset mapping**: Adjust for different home positions

**Configuration Structure**:
```cpp
struct JointMapping {
  float scale;        // 1.0 = 1:1, 0.5 = half speed, etc.
  float offset;       // Home position offset (degrees)
  bool inverted;      // Mirror this joint
  float min_angle;    // Clamp to valid range
  float max_angle;
};

class PositionMapper {
  JointMapping mappings[6];  // Per-joint configuration
  
  float mapPosition(int joint_idx, float leader_angle);
  void loadMappingFromEEPROM();
  void saveMappingToEEPROM();
};
```

**Use Cases**:
- Different arm kinematics
- Asymmetric arms (left vs right)
- Non-1:1 gear ratios
- Mirror bilateral teleoperation (left leader controls right follower)

---

### 3. Telemetry Transmitter Module

**Purpose**: Send follower joint positions back to leader/laptop

**Output Format (JSON)**:
```json
{
  "cmd": "TELEMETRY_STATE",
  "seq": 42,
  "ts": 1000500,
  "follower_joints": [0.0, 45.0, 90.0, 135.0, 90.0, 91.2],
  "errors": [0, 0, 0, 0, 0, 1.2],
  "motor_currents": [1.2, 1.5, 2.1, 0.8, 0.2, 0.15],
  "faults": [0, 0, 0, 0, 0, 0]
}
```

**Transmission**:
- **Frequency**: 100 Hz (real-time feedback for smooth operation)
- **Medium**: USB-CDC (non-blocking, drop if buffer full)

**Key Methods**:
```cpp
class TelemetryTransmitter {
  void queueTelemetryMessage(const float* joint_angles,
                            const float* errors,
                            const float* currents,
                            const uint8_t* faults);
  void update();  // Called from control loop, sends if time window reached
};
```

---

### 4. Synchronization Monitor Module

**Purpose**: Monitor communication health and latency in teleoperation mode

```cpp
class SynchronizationMonitor {
  // Tracks message flow
  uint32_t last_valid_command_ts;    // When we last got valid JOINT_STATE
  uint32_t last_ack_sent_ts;         // When we last sent TELEMETRY_STATE
  
  // Latency tracking
  uint32_t message_latency_ms;       // One-way latency estimate
  uint32_t roundtrip_latency_ms;     // If laptop echoes timestamp
  
  // Detection
  bool isCommandTimeout() const;     // >100ms since last valid command
  bool isHighLatency() const;        // >50ms latency
  bool isCommandGap() const;         // Sequence number gap
  
  // Action
  void handleTimeout();              // Stop motors, raise fault
  void handleHighLatency();          // Log warning, continue
};
```

**Timeout Behavior**:
- **100ms command timeout**: Drop to fail-safe (motors disable)
- **Stricter than VLA mode** because teleoperation is real-time
- If leader loses connection, follower stops immediately

---

## Communication Protocol Comparison

### VLA Inference Mode (Current)
```
Command (Laptop → Follower):
{"cmd":"MOTOR_TARGET","seq":1,"targets":[0,45,90,135,0,0]}
         ↓
Parse in follower → Apply positions
         ↓ 
Response (Follower → Laptop):
{"cmd":"MOTOR_STATUS","seq":1,"positions":[0,45,90,135,0,0]}

Frequency: 10-50 Hz (sporadic, task-driven)
Latency: Moderate (<100ms acceptable)
Timeout: 500ms
```

### Teleoperation Mode (Proposed)
```
Command (Leader → Follower via Laptop):
{"cmd":"JOINT_STATE","seq":42,"leader_joints":[0,45,90,135,90,90],
 "valid_mask":[1,1,1,1,1,1]}
         ↓
Parse in follower → Map leader angles → Target positions
         ↓
Response (Follower → Laptop):
{"cmd":"TELEMETRY_STATE","seq":42,"follower_joints":[0,45,90,135,90,91.2],
 "errors":[0,0,0,0,0,1.2],"motor_currents":[...]}

Frequency: 100 Hz (constant streaming)
Latency: Strict (<50ms for smooth mirroring)
Timeout: 100ms (tight safety margin)
```

---

## Firmware Modification Plan

### Phase 1: Prepare for Dual-Mode (Non-breaking)

**Goal**: Make current VLA code mode-aware without changing behavior

1. **Create `mode_config.h`**:
   ```cpp
   #ifndef OPERATION_MODE
   #define OPERATION_MODE VLA_INFERENCE  // Default
   #endif
   
   #define VLA_INFERENCE 1
   #define TELEOPERATION 2
   ```

2. **Create mode-specific directories**:
   - `src/modules/vla_inference/` (move current heartbeat/command modules)
   - `src/modules/teleoperation/` (new: placeholder until Phase 2)

3. **Create message router** in `comms/message_router.h`:
   ```cpp
   void routeIncomingMessage(const JsonDocument& doc) {
     #if OPERATION_MODE == VLA_INFERENCE
       vla_handlers.routeCommand(doc);
     #elif OPERATION_MODE == TELEOPERATION
       tele_handlers.routeCommand(doc);
     #endif
   }
   ```

4. **Update main.cpp initialization**:
   ```cpp
   void setup() {
     initCommonModules();  // Safety, Motors, Servos (always)
     
     #if OPERATION_MODE == VLA_INFERENCE
       initVLAMode();      // Heartbeat, JSON parser, status TX
     #elif OPERATION_MODE == TELEOPERATION
       initTeleopMode();   // Joint state RX, position mapper, telemetry TX
     #endif
   }
   ```

**Effort**: 4-6 hours (refactoring, no new features)  
**Risk**: Low (VLA mode behavior unchanged)  
**Benefit**: Foundation for Phase 2, clean separation

### Phase 2: Implement Teleoperation Mode

**Goal**: Add full teleoperation capability

1. **Implement JointStateReceiver** (similar to HeartbeatReceiver):
   - Parse JSON with 6 joint angles
   - Sequence tracking
   - Timeout detection

2. **Implement PositionMapper**:
   - Load/save calibration from EEPROM
   - Support multiple mapping profiles

3. **Implement TelemetryTransmitter**:
   - Queue telemetry at 100 Hz
   - Include motor currents, error feedback

4. **Implement SynchronizationMonitor**:
   - Track 100ms timeout
   - Latency measurements

5. **Unit tests**:
   - Mock leader joint inputs
   - Verify position mapping accuracy
   - Test timeout behavior

**Effort**: 8-12 hours (new modules + testing)  
**Risk**: Medium (tight timing requirements)  
**Benefit**: Full teleoperation capability

### Phase 3: Hardware Integration (Leader ESP32)

**Goal**: Complement with leader firmware

1. **Create `leader_esp32/` firmware**:
   - Read potentiometers/encoders (ADC inputs)
   - Publish joint angles at 100 Hz
   - Simple protocol (no safety critical)

2. **Integrate with Laptop coordinator**:
   - Laptop reads from leader
   - Forwards to follower
   - Collects follower telemetry (optional: log for replay)

**Effort**: 6-8 hours (simple, largely existing code patterns)  
**Risk**: Low (hardware-agnostic)  
**Benefit**: Complete teleoperation pipeline

---

## Teleoperation Mode - Safety Considerations

### Motor Disable Hierarchy

```
Priority 1 (Highest): Command Timeout (100ms)
├─ Trigger: No valid JOINT_STATE received for 100ms
├─ Action: Immediate motor disable (EN pin LOW)
└─ Recovery: New JOINT_STATE resumes operation

Priority 2: Safety Fault (same as VLA mode)
├─ Trigger: Stall detection, current overload, etc.
├─ Action: Motors disabled, fault state TX'd
└─ Recovery: Manual reset via RESET_FAULT command

Priority 3: High Latency Warning (50ms)
├─ Trigger: Message latency >50ms
├─ Action: Log warning, continue operation
└─ Recovery: Automatic when latency improves
```

### Fail-Safe Defaults

- **No leader connection**: Follower stays in last-known position (motors enabled, holding position)
- **Communication gap**: Immediate motor disable (fail-safe)
- **Position error too large**: Disable joint (flag in joint_faults)
- **Current spike**: Disable motor, raise fault

---

## Integration with Existing Modules

### Shared Components (Both Modes)

```
MotorController (PID)
  ├─ VLA mode: Target from JSON command
  └─ Tele mode: Target from position mapper

ServoManager (LEDC PWM)
  ├─ VLA mode: Target from JSON command
  └─ Tele mode: Target from position mapper

SafetyTask
  ├─ VLA mode: 500ms heartbeat timeout
  └─ Tele mode: 100ms command timeout + same faults

TelemetryCollector
  ├─ VLA mode: Collected at 10Hz, sent on demand
  └─ Tele mode: Collected at 100Hz, streamed continuously
```

### Mode-Specific Component Lifecycle

```
VLA Mode Startup:
  1. HeartbeatReceiver starts listening
  2. Motors stay disabled until first heartbeat
  3. Once connected, motors enable (if no other faults)

Teleoperation Mode Startup:
  1. PositionMapper loads calibration
  2. Motors enabled (ready to receive commands)
  3. Motors disable if no JOINT_STATE for 100ms

Mode Switching (Runtime, Phase 2+):
  1. Send {"cmd":"SET_MODE","mode":"TELEOPERATION"}
  2. Firmware stops current mode listeners
  3. Firmware initializes new mode
  4. Motors disable (safe transition)
  5. Return {"cmd":"MODE_CHANGED_ACK","mode":"TELEOPERATION"}
```

---

## Development Roadmap

### Week 1-2: Refactoring (Phase 1)
- [ ] Create mode configuration system
- [ ] Reorganize modules into mode directories
- [ ] Implement message router
- [ ] Update main.cpp
- [ ] Run existing VLA tests (should all pass)

### Week 3-4: Teleoperation Core (Phase 2)
- [ ] Implement JointStateReceiver
- [ ] Implement PositionMapper with EEPROM support
- [ ] Implement TelemetryTransmitter
- [ ] Implement SynchronizationMonitor
- [ ] Write unit tests (20+ tests)

### Week 5-6: Integration & Testing (Phase 2)
- [ ] Integrate with SafetyTask
- [ ] Test mode-aware timeout handling
- [ ] Integration tests (VLA + Tele switching)
- [ ] Performance profiling (latency, RAM usage)

### Week 7-8: Leader Firmware (Phase 3)
- [ ] Create leader_esp32 project structure
- [ ] Implement sensor reader (ADC potentiometers)
- [ ] Implement joint publisher (100 Hz)
- [ ] Simple test (sensor → leader → follower)

---

## Questions for Architecture Review

1. **Position Mapping Complexity**: Should we support per-joint calibration from day 1, or just identity mapping for initial teleoperation?

2. **Laptop Coordination**: Does the laptop act as:
   - Simple router (leader → follower only)?
   - Data logger (records telemetry for VLA training)?
   - Safety monitor (enforces additional constraints)?

3. **Latency Target**: Is 50ms one-way latency acceptable, or need tighter (<30ms)?

4. **Wireless Future**: Should we architect for WiFi uplink (leader → WiFi → laptop → WiFi → follower), or assume USB for Phase 1?

5. **Encoder vs Potentiometer**: What sensors will leader have? Affects calibration complexity.

6. **Simultaneous Modes**: Should firmware support per-joint mode (some joints VLA, some tele), or full-system mode only?

---

## Comparison: Current vs Proposed

### Current VLA Inference Mode
✅ Core implementation active  
✅ 400 Hz control loop  
✅ Safety timeout: 500ms  
✅ JSON command protocol  
✅ Motor control + homing command support  
🚧 Documentation and integration still being refined  

### Teleoperation Mode
✅ Compile-time mode wiring in place  
✅ Leader JOINT_STATE path and bridge forwarding in place  
✅ Follower teleop command handling includes `ENABLE_MOTORS`, `RESET_FAULT`, `HOME_ZERO`, `HOME_STALLGUARD`  
⏳ Safety timeout: 100ms (tighter)  
⏳ Follower `TELEMETRY_STATE` expansion still pending  
⏳ Position mapper + sync monitor still evolving  
⏳ New: Telemetry streaming (100 Hz)  

**Current Risk Level**: Medium (safety-critical coordination still under active iteration)  
**Benefit**: Full teleoperation data collection capability once telemetry + ROS2 teleop runtime are finalized  

---

## Conclusion

**Current Status**: 🚧 VLA + teleoperation firmware path is functional but still in active development  
**Proposed Direction**: Dual-mode firmware supporting both VLA inference and teleoperation  
**Architecture Pattern**: Mode-aware modular firmware with shared safety/control components  
**Timeline**: Continue iterative hardening of teleoperation, telemetry, and ROS2 integration

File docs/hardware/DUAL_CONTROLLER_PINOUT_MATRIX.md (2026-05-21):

# Dual-Controller Pinout & Wiring Matrix

Consolidated pinout/GPIO reference for `leader_esp32`, `follower_esp32`, 4× TMC2209, servos, inter-board UART, and power rails.

Primary source: `docs/references/SixEyes Technical Reference 2.txt`.

---

## 1) Leader ESP32-C6 SuperMini (Teleoperation Controller)

### Analog Inputs (Potentiometers)

| Joint Input | ESP32-C6 GPIO |
|:---|:---|
| Pot 1 | GPIO0 |
| Pot 2 | GPIO1 |
| Pot 3 | GPIO2 |
| Pot 4 | GPIO3 |
| Pot 5 | GPIO4 |
| Pot 6 | GPIO6 |

### UART to Follower (Dedicated Inter-Board Link)

| Signal | Leader GPIO | Connects To (Follower) |
|:---|:---|:---|
| TX | GPIO17 | RX on GPIO18 |
| RX | GPIO18 | TX on GPIO17 |

### Power (Leader)

| Rail | Notes |
|:-----|:---|
| 3.3V | From follower PCB or local LDO (standalone mode) |
| GND | Common ground with follower required |

---

## 2) Follower ESP32-S3 (Actuated Arm Controller)

### TMC2209 Stepper Driver Channels (x4)

| Channel | Joint | STEP | DIR | EN | PDN_UART |
|:---|:---|:-----|:----|:---|:---|
| J1 | Base | GPIO12 | GPIO11 | GPIO14 (shared EN_ALL) | GPIO13 |
| J2 | Shoulder A | GPIO9 | GPIO8 | GPIO14 (shared EN_ALL) | GPIO10 |
| J3 | Shoulder B | GPIO15 | GPIO7 | GPIO14 (shared EN_ALL) | GPIO16 |
| J4 | Elbow | GPIO5 | GPIO4 | GPIO14 (shared EN_ALL) | GPIO6 |

Notes:
- EN control is safety-gated in firmware.
- PDN_UART lines use series resistor + pull-up per hardware reference.

### Servo Outputs (x3)

| Function | Follower GPIO | Power Rail |
|:---|:---|:---|
| Wrist Pitch | GPIO40 | 6.6V |
| Wrist Yaw | GPIO41 | 6.6V |
| Gripper | GPIO42 | 6.6V |

### SD Card SPI + Detect

| Signal | Follower GPIO |
|:---|:---|
| SD_MOSI | GPIO35 |
| SD_SCK | GPIO36 |
| SD_MISO | GPIO37 |
| SD_CS | GPIO38 |
| SD_CD | GPIO39 |

### UART to Leader (Dedicated Inter-Board Link)

| Signal | Follower GPIO | Connects To (Leader) |
|:---|:---|:---|
| RX | GPIO18 | TX on GPIO17 |
| TX | GPIO17 | RX on GPIO18 |

### USB to Laptop

| Interface | Notes |
|:---|:---|
| Native USB-CDC | Follower↔Laptop command/telemetry path |

---

## 3) Power Rails & Distribution

| Rail | Source | Primary Loads |
|:-----|:---|:---|
| 24V | Main input (≥10A recommended) | TMC2209 VM, onboard buck converters |
| 6.6V | XL4016 buck (on PCB) | 3× servos |
| 3.3V | MP1584 buck (on PCB) | ESP32 logic, TMC2209 VIO, digital logic |

Grounding:
- Use common ground star point near power entry.
- Keep servo high-current return paths away from MCU signal ground.

---

## 4) Camera Architecture (Revised)

Camera is not routed through follower PCB.

| Path | Connection |
|:-----|:---|
| Camera stream | Camera → USB cable → Laptop |

Embedded boards focus on motor/sensor/safety/telemetry; laptop handles camera + VLA stack.

---

## 5) Firmware Mapping Status (Mar 2026)

| Item | Status | Firmware Reference |
|:-----|:---|:---|
| Leader ADC pins GPIO0,1,2,3,4,6 | ✅ Aligned | `sixeyes/firmware/leader_esp32/src/main.cpp` (ESP32-C6 SuperMini) |
| Follower TMC2209 pin map | ✅ Aligned | `sixeyes/firmware/follower_esp32/src/modules/drivers/tmc2209/tmc2209_config.h` |
| Follower UART pins GPIO18/17 | ✅ Aligned | `sixeyes/firmware/follower_esp32/src/modules/config/board_config.h`, `.../uart_leader.cpp` |
| Servo outputs GPIO40/41/42 | ✅ Aligned | `sixeyes/firmware/follower_esp32/src/modules/servo_control/servo_manager.h` |

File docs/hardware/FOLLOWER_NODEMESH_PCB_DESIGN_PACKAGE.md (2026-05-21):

# SixEyes Follower PCB Design Package (NodeMesh-Aware)

Migration note: active NodeMesh firmware and NodeMesh-specific architecture docs are maintained in [https://github.com/SixEyes-Open-Source/nodemesh](https://github.com/SixEyes-Open-Source/nodemesh).

This document is a practical, copy-into-CAD checklist for the first follower PCB prototype.

Design intent for this revision:
- Single-layer routing for prototype bring-up.
- Use jumper wires for unavoidable crossovers and to stitch ground islands/pours.
- Keep compatibility with current follower firmware and NodeMesh direction.
- Through-hole parts only for this prototype spin.

---

## 1) Locked Pinout (Firmware-Verified)

Authoritative mapping is based on current follower firmware and NodeMesh pin docs.

### Stepper Drivers (TMC2209 x4)

| Channel | Joint | STEP | DIR | EN | PDN_UART |
|:--|:--|:--|:--|:--|:--|
| J1 | Base | GPIO12 | GPIO11 | GPIO14 (shared EN_ALL) | GPIO13 |
| J2 | Shoulder A | GPIO9 | GPIO8 | GPIO14 (shared EN_ALL) | GPIO10 |
| J3 | Shoulder B | GPIO15 | GPIO7 | GPIO14 (shared EN_ALL) | GPIO16 |
| J4 | Elbow | GPIO5 | GPIO4 | GPIO14 (shared EN_ALL) | GPIO6 |

### Servo PWM Outputs

| Function | GPIO | Net Name |
|:--|:--|:--|
| Wrist Pitch | GPIO40 | SERVO_WRIST_PITCH |
| Wrist Yaw | GPIO41 | SERVO_WRIST_YAW |
| Gripper | GPIO42 | SERVO_GRIPPER |

### Inter-Board UART (Leader <-> Follower)

| Signal | Follower GPIO | Net Name |
|:--|:--|:--|
| RX (from leader TX) | GPIO18 | UART_LEADER_RX |
| TX (to leader RX) | GPIO17 | UART_LEADER_TX |

### Power Nets

| Net | Notes |
|:--|:--|
| +24V_MOTOR | TMC VMOT rail input |
| +6V6_SERVO | Servo rail from buck converter |
| +3V3_LOGIC | ESP32-S3 logic, TMC VIO, pull-ups |
| GND | Common ground |

### Reserved/Free GPIO in this revision

- Leave unconnected due to board constraints: GPIO3, GPIO46, GPIO19, GPIO20, GPIO45, GPIO0, GPIO44, GPIO43
- Reserved/free for future use: GPIO21, GPIO47, GPIO1, GPIO2
- Onboard RGB LED: GPIO48

---

## 2) Net Naming Standard (Use Exactly)

Use these exact net names in schematic and PCB for easy firmware cross-check:

- STEP_J1, DIR_J1, PDN_J1
- STEP_J2, DIR_J2, PDN_J2
- STEP_J3, DIR_J3, PDN_J3
- STEP_J4, DIR_J4, PDN_J4
- EN_ALL
- SERVO_WRIST_PITCH, SERVO_WRIST_YAW, SERVO_GRIPPER
- UART_LEADER_RX, UART_LEADER_TX
- SD_SCK, SD_MISO, SD_MOSI, SD_CS, SD_CD
- +24V_MOTOR, +6V6_SERVO, +3V3_LOGIC, GND

Optional debug nets (recommended):
- TP_EN_ALL
- TP_PDN_J1, TP_PDN_J2, TP_PDN_J3, TP_PDN_J4
- TP_UART_RX, TP_UART_TX

---

## 3) Full Netlist by Connector/Block

## 3.1 ESP32-S3 DevKitC-1 Header to Nets

| MCU GPIO | Net |
|:--|:--|
| 14 | EN_ALL |
| 13 | PDN_J1 |
| 12 | STEP_J1 |
| 11 | DIR_J1 |
| 10 | PDN_J2 |
| 9 | STEP_J2 |
| 8 | DIR_J2 |
| 18 | UART_LEADER_RX |
| 17 | UART_LEADER_TX |
| 16 | PDN_J3 |
| 15 | STEP_J3 |
| 7 | DIR_J3 |
| 6 | PDN_J4 |
| 5 | STEP_J4 |
| 4 | DIR_J4 |
| 35 | SD_MOSI |
| 36 | SD_SCK |
| 37 | SD_MISO |
| 38 | SD_CS |
| 39 | SD_CD |
| 40 | SERVO_WRIST_PITCH |
| 41 | SERVO_WRIST_YAW |
| 42 | SERVO_GRIPPER |

Power/header pins:
- 3V3 -> +3V3_LOGIC
- GND -> GND

## 3.2 TMC2209 Drivers (x4)

Per driver block Jx (stepstick-style 2x08 module):
- STEP pin -> STEP_Jx
- DIR pin -> DIR_Jx
- EN pin -> EN_ALL
- PDN pin -> PDN_Jx
- VIO / VDD -> +3V3_LOGIC
- VMOT / VM -> +24V_MOTOR
- GND pins -> GND
- Motor outputs A1/A2/B1/B2 -> matching motor connector Jx_MOTOR

Reference socket orientation used in this project:
- Logic row: EN, MS1, MS2, PDN, CLK, STEP, DIR
- Power/motor row: VM, GND, A2, A1, B1, B2, VDD, GND
- MS1, MS2, and CLK are reserved for future use unless explicitly wired.

Recommended support passives per driver:
- 100 nF through-hole decoupler at VIO-to-GND.
- 4.7 k pull-up on each PDN_Jx to +3V3_LOGIC.
- Optional 0R (through-hole axial) series link on each PDN_Jx for debug isolation.
- Bulk capacitor near VMOT entry area (see passives section).

## 3.3 Stepper Motor Outputs (6-pin JST, 4 used)

Use one 6-pin JST connector per NEMA17 stepper channel for 6-wire bipolar motors, leaving center taps open.

Per motor connector Jx_MOTOR (x4):
- Pin 1: A+ (TMC A1 / OUT1 / 1A)
- Pin 2: NC (center tap, leave open)
- Pin 3: A- (TMC A2 / OUT2 / 2A)
- Pin 4: B+ (TMC B1 / OUT3 / 1B)
- Pin 5: NC (center tap, leave open)
- Pin 6: B- (TMC B2 / OUT4 / 2B)

Channel mapping:
- J1_MOTOR -> TMC2209 J1 A1/A2/B1/B2 to connector pins 1/3/4/6
- J2_MOTOR -> TMC2209 J2 A1/A2/B1/B2 to connector pins 1/3/4/6
- J3_MOTOR -> TMC2209 J3 A1/A2/B1/B2 to connector pins 1/3/4/6
- J4_MOTOR -> TMC2209 J4 A1/A2/B1/B2 to connector pins 1/3/4/6

## 3.4 Servo Connectors (3-pin JST each)

For each servo connector:
- Pin 1: GND
- Pin 2: +6V6_SERVO
- Pin 3: Signal

Signal map:
- Servo 1 signal -> SERVO_WRIST_PITCH
- Servo 2 signal -> SERVO_WRIST_YAW
- Servo 3 signal -> SERVO_GRIPPER

## 3.5 Leader/Follower UART Connector

4-pin recommended header:
- Pin 1: GND
- Pin 2: UART_LEADER_RX (leader TX)
- Pin 3: UART_LEADER_TX (leader RX)
- Pin 4: +3V3_LOGIC (optional, only if power-sharing is required)

## 3.6 Power Input and Rails

Power terminals in this revision (5x 2-pin terminal blocks):
- J_PWR1 (PWR-IN-24V): external 24V input -> +24V_MOTOR, GND
- J_PWR2 (24V-OUT-BUCK3V3-IN): +24V_MOTOR, GND output to 3.3V buck input
- J_PWR3 (24V-OUT-BUCK6V6-IN): +24V_MOTOR, GND output to 6.6V buck input
- J_PWR4 (BUCK3V3-OUT-IN): external buck 3.3V output input -> +3V3_LOGIC, GND
- J_PWR5 (BUCK6V6-OUT-IN): external buck 6.6V output input -> +6V6_SERVO, GND

This architecture intentionally keeps buck converters off-board for prototype flexibility.

Ground strategy for single-layer prototype:
- One primary ground pour on bottom.
- If pour is segmented by traces, stitch segments with dedicated wire jumpers (labeled GND_JMP1, GND_JMP2, ...).

## 3.7 SD Card Reader Board (SPI) Pinout

Use a through-hole 6-pin socket (female) for direct SD module plug-in, no flying jumpers.

ESP32-S3 to SD net mapping:
- GPIO36 -> SD_SCK
- GPIO37 -> SD_MISO
- GPIO35 -> SD_MOSI
- GPIO38 -> SD_CS
- GPIO39 -> SD_CD (card detect, optional input)

Recommended SD socket pinout (H_SD1, 1x06):
- Pin 1: +3V3_LOGIC (to SD VCC)
- Pin 2: GND
- Pin 3: SD_SCK
- Pin 4: SD_MISO
- Pin 5: SD_MOSI
- Pin 6: SD_CS

Card detect wiring:
- Route SD_CD to a dedicated test pad or optional 1-pin header (for modules exposing CD switch).

Wire-up to common SD module labels:
- SD_SCK -> CLK
- SD_MISO -> DO / MISO
- SD_MOSI -> DI / MOSI
- SD_CS -> CS / SS

Important:
- Use 3.3V SD modules for direct ESP32-S3 logic compatibility.
- Keep SD SPI traces short and away from motor phase traces.

---

## 4) Footprints and Package Choices

Use common KiCad library footprints where possible to avoid custom risk.

Prototype policy for this revision:
- Through-hole parts only.
- No SMD passives in this build.

## 4.1 Recommended Footprint Map

| Ref Type | Suggested Footprint |
|:--|:--|
| ESP32-S3 DevKitC-1 socket headers | PinSocket_1x19_P2.54mm_Vertical x2 (adjust pin count to module) |
| TMC2209 carrier sockets | PinSocket_2x08_P2.54mm_Vertical per driver (through-hole female socket) |
| Servo connectors | JST_XH_B3B-XH-A_1x03_P2.50mm_Vertical |
| Motor outputs (6-pin, 4 active) | JST_XH_B6B-XH-A_1x06_P2.50mm_Vertical (or same-series equivalent matching your harness pitch) |
| Power terminals (J_PWR1..J_PWR5) | TerminalBlock_1x02_P5.08mm |
| UART link | PinHeader_1x04_P2.54mm_Vertical |
| SD module direct socket | PinSocket_1x06_P2.54mm_Vertical |
| Test points | TestPoint_Pad_D1.5mm |
| Mount holes | MountingHole_3.2mm_M3 |
| Through-hole resistors | R_Axial_DIN0207_L6.3mm_D2.5mm_P7.62mm_Horizontal |
| Through-hole electrolytics | CP_Radial_D8.0mm_P3.50mm, CP_Radial_D10.0mm_P5.00mm (based on value/voltage) |
| Through-hole film/ceramic caps | C_Disc_D5.0mm_W2.5mm_P5.00mm or C_Rect_L7.2mm_W2.5mm_P5.00mm |

If your exact connector stock differs, keep net names and pin order unchanged and only swap footprint package.

## 4.1.1 Devboard Header Footprints (Explicit)

All controller/driver modules are treated as pluggable devboards and must connect through 2.54 mm through-hole headers.

ESP32-S3 devboard (on main PCB):
- PCB footprint: PinSocket_1x19_P2.54mm_Vertical x2 (female socket on PCB).
- Devboard mating part: PinHeader_1x19_P2.54mm_Vertical x2 (male pins soldered on ESP32 devboard).

TMC2209 devboards (each driver on main PCB):
- PCB footprint: PinSocket_2x08_P2.54mm_Vertical per driver.
- Devboard mating part: PinHeader_2x08_P2.54mm_Vertical on each TMC board.

Alternative if you want lower stack height:
- Use PinHeader_* on PCB and PinSocket_* on module side, but keep 2.54 mm pitch and same pin count.

Mechanical/orientation notes:
- Add clear silkscreen marker for pin 1 on every devboard socket row.
- Keep at least 2.0 mm courtyard clearance around sockets for insertion/removal.
- Lock one orientation only (no mirrored socket rows).
- Place TMC sockets so EN/STEP/DIR/PDN side is consistent across J1..J4.

## 4.2 Discrete Passives BOM (Through-Hole)

These are the minimum recommended passives for stable first-spin bring-up.

| RefDes | Qty | Value | Type | Voltage/Power | Net Placement |
|:--|:--:|:--|:--|:--|:--|
| C1 | 1 | 470 uF | Electrolytic radial | 35V min | +24V_MOTOR to GND at power entry |
| C2 | 1 | 1 uF | Film/ceramic THT | 50V min | +24V_MOTOR to GND near TMC bank |
| C3 | 1 | 100 nF | Ceramic disc THT | 50V min | +24V_MOTOR to GND near TMC bank |
| C4 | 1 | 1000 uF | Electrolytic radial | 16V min | +6V6_SERVO to GND at servo power fan-out |
| C5 | 1 | 100 nF | Ceramic disc THT | 25V min | +6V6_SERVO to GND near servo connector cluster |
| C6 | 1 | 220 uF | Electrolytic radial | 10V min | +3V3_LOGIC to GND near ESP32 socket |
| C7-C10 | 4 | 100 nF | Ceramic disc THT | 25V min | Each TMC VIO pin to nearest GND |
| C11 | 1 | 100 nF | Ceramic disc THT | 25V min | +3V3_LOGIC to GND near UART header |
| C12 | 1 | 10 uF | Electrolytic radial | 10V min | +3V3_LOGIC to GND near SD header |
| C13 | 1 | 100 nF | Ceramic disc THT | 25V min | +3V3_LOGIC to GND near SD header |
| R1-R4 | 4 | 4.7 k | Axial resistor | 1/4W | PDN_J1..PDN_J4 pull-up to +3V3_LOGIC |
| R5-R8 | 4 | 0R link | Axial resistor | 1/4W | Series on PDN_J1..PDN_J4 (optional debug isolation) |
| R9-R11 | 3 | 100 k | Axial resistor | 1/4W | Servo signal pulldown to GND (one per SERVO_* net) |
| R12-R13 | 2 | 220 ohm | Axial resistor | 1/4W | Series on UART_LEADER_RX and UART_LEADER_TX (optional EMI damping) |
| R14-R17 | 4 | 33 ohm | Axial resistor | 1/4W | Series on SD_SCK/SD_MISO/SD_MOSI/SD_CS (optional signal damping) |

Notes:
- R5-R8 can be DNI if you prefer direct PDN routing.
- R12-R13 can be DNI if UART link is short and clean.
- Keep all capacitor leads short, especially C7-C10 around TMC VIO pins.

## 4.3 Discrete Passives Wiring Guide

Follow this order for clean bring-up.

1. 24V input filtering:
- Wire C1 directly across +24V_MOTOR and GND at the board input terminal.
- Place C2 and C3 in parallel across +24V_MOTOR and GND near the first/center TMC driver socket.

2. 6.6V servo rail stabilization:
- Wire C4 across +6V6_SERVO and GND at the servo rail branch point.
- Add C5 near the servo connector cluster between +6V6_SERVO and GND.

3. 3.3V logic rail stabilization:
- Place C6 across +3V3_LOGIC and GND near ESP32 power entry pins.
- Place C11 across +3V3_LOGIC and GND near UART header/logic edge.
- Place C12 and C13 across +3V3_LOGIC and GND near the SD header.

4. Per-driver logic decoupling:
- Place C7, C8, C9, C10 each from TMC VIO to nearest GND on J1..J4 respectively.

5. PDN conditioning:
- Route PDN_J1..PDN_J4 from ESP32 to corresponding drivers.
- Add R1-R4 as pull-ups from each PDN_Jx net to +3V3_LOGIC.
- Insert R5-R8 in series on each PDN_Jx trace (ESP32 side -> resistor -> driver side).

6. Servo signal default-safe state:
- Add R9-R11 from SERVO_WRIST_PITCH, SERVO_WRIST_YAW, SERVO_GRIPPER to GND.

7. UART damping:
- Place R12 in series on UART_LEADER_RX and R13 in series on UART_LEADER_TX close to ESP32 header side.

8. SD SPI conditioning:
- Route SD_SCK, SD_MISO, SD_MOSI, SD_CS from ESP32 pins to H_SD1.
- Optionally place R14-R17 in series on each SD line near the ESP32 side.

## 4.4 Optional Custom Footprint Code (KiCad .kicad_mod Template)

Use this only when you need a custom jumper pad footprint for GND stitching wires.

```scheme
(footprint "WireJumper_1x02_P2.54mm" (version 20221018) (generator "manual")
  (layer "F.Cu")
  (descr "2-pad wire jumper footprint for single-layer bridges")
  (attr through_hole)
  (fp_text reference "JP?" (at 0 -2.2) (layer "F.SilkS")
    (effects (font (size 1 1) (thickness 0.15)))
  )
  (fp_text value "WIRE_JUMPER" (at 0 2.2) (layer "F.Fab")
    (effects (font (size 1 1) (thickness 0.15)))
  )
  (fp_line (start -2 -1.3) (end 2 -1.3) (layer "F.SilkS") (width 0.12))
  (fp_line (start -2 1.3) (end 2 1.3) (layer "F.SilkS") (width 0.12))
  (pad "1" thru_hole circle (at -1.27 0) (size 1.8 1.8) (drill 0.9)
    (layers "*.Cu" "*.Mask")
  )
  (pad "2" thru_hole circle (at 1.27 0) (size 1.8 1.8) (drill 0.9)
    (layers "*.Cu" "*.Mask")
  )
)
```

Place these as:
- Signal jumpers for unavoidable single-layer crossings.
- Ground jumpers between disconnected ground-pour islands.

## 4.5 Schematic Symbols (What To Use)

Use hierarchical, connector-style symbols for devboards so pin names match firmware nets directly.

Recommended symbol naming in your schematic library:
- U1: ESP32_S3_DEVBOARD_2x19
- U2-U5: TMC2209_DEVBOARD_2x08
- J1_MOTOR..J4_MOTOR: JST6_STEPPER_4USED
- J_SERVO1..J_SERVO3: JST3_SERVO
- H_UART1: HDR_1x04_UART
- H_SD1: HDR_1x06_SD_SPI

### 4.5.1 ESP32-S3 Devboard Symbol (U1)

Create one multi-pin symbol named ESP32_S3_DEVBOARD_2x19 with at least the used pins below exposed and labeled exactly:

| Symbol Pin Name | MCU GPIO | Net Label to Wire |
|:--|:--|:--|
| GPIO14 | 14 | EN_ALL |
| GPIO13 | 13 | PDN_J1 |
| GPIO12 | 12 | STEP_J1 |
| GPIO11 | 11 | DIR_J1 |
| GPIO10 | 10 | PDN_J2 |
| GPIO9 | 9 | STEP_J2 |
| GPIO8 | 8 | DIR_J2 |
| GPIO18 | 18 | UART_LEADER_RX |
| GPIO17 | 17 | UART_LEADER_TX |
| GPIO16 | 16 | PDN_J3 |
| GPIO15 | 15 | STEP_J3 |
| GPIO7 | 7 | DIR_J3 |
| GPIO6 | 6 | PDN_J4 |
| GPIO5 | 5 | STEP_J4 |
| GPIO4 | 4 | DIR_J4 |
| GPIO35 | 35 | SD_MOSI |
| GPIO36 | 36 | SD_SCK |
| GPIO37 | 37 | SD_MISO |
| GPIO38 | 38 | SD_CS |
| GPIO39 | 39 | SD_CD |
| GPIO40 | 40 | SERVO_WRIST_PITCH |
| GPIO41 | 41 | SERVO_WRIST_YAW |
| GPIO42 | 42 | SERVO_GRIPPER |
| 3V3 | - | +3V3_LOGIC |
| GND | - | GND |

Symbol rules:
- Mark GPIO pins as bidirectional/passive (project preference), power pins as power input.
- Keep pin names as GPIOxx text, not custom aliases.

### 4.5.2 TMC2209 Devboard Symbol (U2-U5)

Create symbol TMC2209_DEVBOARD_2x08 with these functional pins:

| Symbol Pin Name | Net (Per Channel x) |
|:--|:--|
| STEP | STEP_Jx |
| DIR | DIR_Jx |
| EN | EN_ALL |
| PDN_UART | PDN_Jx |
| VIO | +3V3_LOGIC |
| VMOT | +24V_MOTOR |
| GND | GND |
| A1 | Jx_MOTOR_PIN3 (1A) |
| A2 | Jx_MOTOR_PIN2 (2A) |
| B1 | Jx_MOTOR_PIN1 (1B) |
| B2 | Jx_MOTOR_PIN4 (2B) |

Instantiate four copies:
- U2 (J1), U3 (J2), U4 (J3), U5 (J4)

### 4.5.3 JST-6 Stepper Connector Symbol (Jx_MOTOR)

Create symbol JST6_STEPPER_4USED (single-row 6-pin connector):

| Connector Pin | Net |
|:--|:--|
| 1 | Jx_MOTOR_PIN1 / A+ |
| 2 | NC (center tap open) |
| 3 | Jx_MOTOR_PIN2 / A- |
| 4 | Jx_MOTOR_PIN3 / B+ |
| 5 | NC (center tap open) |
| 6 | Jx_MOTOR_PIN4 / B- |

In KiCad, set pins 5 and 6 as passive and mark explicitly as NC with no-connect flags.

### 4.5.4 JST-3 Servo Connector Symbol (J_SERVOx)

Create symbol JST3_SERVO:

| Connector Pin | Net |
|:--|:--|
| 1 | GND |
| 2 | +6V6_SERVO |
| 3 | SERVO_* (per channel) |

Use three instances with signal nets:
- J_SERVO1 -> SERVO_WRIST_PITCH
- J_SERVO2 -> SERVO_WRIST_YAW
- J_SERVO3 -> SERVO_GRIPPER

### 4.5.5 UART Header Symbol (H_UART1)

Create symbol HDR_1x04_UART:

| Header Pin | Net |
|:--|:--|
| 1 | GND |
| 2 | UART_LEADER_RX |
| 3 | UART_LEADER_TX |
| 4 | +3V3_LOGIC (optional) |

### 4.5.6 SD Header Symbol (H_SD1)

Create symbol HDR_1x06_SD_SPI (mated to PinSocket_1x06_P2.54mm_Vertical on PCB):

| Header Pin | Net |
|:--|:--|
| 1 | +3V3_LOGIC |
| 2 | GND |
| 3 | SD_SCK |
| 4 | SD_MISO |
| 5 | SD_MOSI |
| 6 | SD_CS |

Add `SD_CD` as a separate 1-pin symbol/testpoint (for card detect input).

### 4.5.7 Power Symbols and Net Labels

Use global power symbols and labels:
- +24V_MOTOR
- +6V6_SERVO
- +3V3_LOGIC
- GND

For readability, place net labels on every cross-sheet entry even if wires are continuous.

---

## 5) Trace Width, Clearance, and Via Rules

These are safe prototype defaults for 1 oz copper, 2-layer-capable fab, but routed as single-layer where possible.

## 5.1 Net Class Rules (Recommended)

| Net Class | Width | Clearance | Via Drill / Dia | Applies To |
|:--|:--|:--|:--|:--|
| SIGNAL_FINE | 0.25 mm (10 mil) | 0.20 mm (8 mil) | 0.30 / 0.60 mm | STEP/DIR/PDN/UART/servo PWM |
| SIGNAL_STD | 0.30 mm (12 mil) | 0.20 mm (8 mil) | 0.30 / 0.60 mm | Generic logic |
| PWR_3V3_6V6 | 0.60 mm (24 mil) | 0.25 mm (10 mil) | 0.40 / 0.80 mm | +3V3_LOGIC, +6V6_SERVO trunks |
| PWR_24V | 1.00 mm (40 mil) | 0.30 mm (12 mil) | 0.40 / 0.80 mm | +24V_MOTOR trunk |
| GND_RETURN | 1.20 mm (47 mil) where traced, otherwise pour | 0.25 mm (10 mil) | 0.40 / 0.80 mm | Ground returns and links |

## 5.2 High-Current Guidance

- Keep +24V_MOTOR and motor return paths short and wide.
- Use local bulk capacitance at motor power entry (start with 220 uF to 470 uF electrolytic + 1 uF + 100 nF ceramics nearby).
- Keep servo rail trunk wide (at least 0.8 mm if space allows) from regulator to servo connector fan-out.

## 5.3 Single-Layer + Jumper Strategy

- Route power trunks first.
- Route STEP/DIR/PDN next as short direct lines.
- Drop labeled wire-jumper footprints where crossing is unavoidable.
- After autorouter/manual route, inspect ground pour islands; bridge each orphan island with explicit GND jumper wire.

---

## 6) Spacing and Placement Rules (Practical)

- Keep at least 3 mm creepage between +24V_MOTOR and low-voltage signal zones where feasible.
- Place TMC2209 modules in one row with consistent orientation.
- Keep ESP32 module away from motor phase traces and buck inductors.
- Keep UART and PDN traces away from motor outputs; cross at 90 degrees when unavoidable.
- Place test points near the ESP32 edge for probe access.

---

## 7) ERC/DRC Checklist Before Fabrication

Schematic/ERC:
- EN_ALL only goes to all four TMC EN pins.
- PDN_J1..PDN_J4 are unique and not tied together.
- UART_LEADER_RX/TX are correctly crossed to leader board.
- All servo connectors have GND and +6V6_SERVO in correct pin order.
- All stepper JST-6 connectors map active phases to pins 1/3/4/6 with pins 2 and 5 left NC.
- SD header maps exactly: 36/37/35/38 to SD_SCK/SD_MISO/SD_MOSI/SD_CS, and SD_CD on GPIO39.
- All listed passives are through-hole package footprints (no SMD passives).

PCB/DRC:
- No unrouted nets.
- No isolated copper islands left unconnected unless intentional.
- Ground pour continuity verified end-to-end with continuity tool.
- All jumper wires represented in schematic as net ties or jumper refs.

Bring-up:
- Power-on with no motors first, check +3V3_LOGIC and +6V6_SERVO.
- Verify EN_ALL toggles and each PDN_Jx can be driven independently.
- Verify UART link before motion test.

---

## 8) NodeMesh Notes for This Follower Board

For this follower motor board revision:
- Keep the board focused on motion/servo/UART.
- SD SPI header is optional for NodeMesh expansion and should use GPIO36/37/35/38 mapping above, with optional SD_CD on GPIO39.

This keeps the follower board modular and consistent with NodeMesh partitioning.

---

## 9) Quick Copy Block for CAD Project Notes

Pin map summary:
- STEP: GPIO12,9,15,5
- DIR: GPIO11,8,7,4
- EN_ALL: GPIO14
- PDN: GPIO13,10,16,6
- Servo PWM: GPIO40,41,42
- UART: RX GPIO18, TX GPIO17
- SD SPI: SCK GPIO36, MISO GPIO37, MOSI GPIO35, CS GPIO38, CD GPIO39

Prototype constraints:
- Single-layer priority.
- Use labeled jumper wires for crossings and GND pour stitching.
- Use wide power traces and keep motor-current loops compact.
- Use through-hole components and JST XH-style connectors for this prototype.

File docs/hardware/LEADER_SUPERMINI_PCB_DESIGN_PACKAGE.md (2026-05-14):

# SixEyes Leader PCB Design Package (ESP32-C6 SuperMini)

This document is a practical, copy-into-CAD checklist for the leader teleoperation PCB.

Design intent for this revision:
- Single-layer routing for prototype bring-up.
- Through-hole parts only for this prototype spin.
- ESP32-C6 SuperMini connected as a pluggable devboard via header pins.
- Board function is analog capture + UART link (no motor power stage on leader board).

---

## 1) Locked Pinout (Firmware-Verified)

Authoritative mapping is based on current leader firmware.

### Potentiometer Inputs (6 channels)

| Joint Input | ESP32-C6 GPIO | Net Name |
|:--|:--|:--|
| Pot 1 | GPIO0 | POT1_WIPER |
| Pot 2 | GPIO1 | POT2_WIPER |
| Pot 3 | GPIO2 | POT3_WIPER |
| Pot 4 | GPIO3 | POT4_WIPER |
| Pot 5 | GPIO4 | POT5_WIPER |
| Pot 6 | GPIO6 | POT6_WIPER |

### Inter-Board UART (Leader -> Follower)

| Signal | Leader GPIO | Net Name |
|:--|:--|:--|
| TX (to follower RX) | GPIO17 | UART_FOLLOWER_RX |
| RX (from follower TX) | GPIO18 | UART_FOLLOWER_TX |

### Power Nets

| Net | Notes |
|:--|:--|
| +3V3_LOGIC | Main logic rail for ESP32-C6 and pots |
| GND | Common ground (must be shared with follower/laptop side) |

---

## 2) Net Naming Standard (Use Exactly)

Use these exact net names in schematic and PCB:

- POT1_WIPER, POT2_WIPER, POT3_WIPER, POT4_WIPER, POT5_WIPER, POT6_WIPER
- POT_BUS_3V3, POT_BUS_GND
- UART_FOLLOWER_RX, UART_FOLLOWER_TX
- +3V3_LOGIC, GND

Optional debug nets:
- TP_POT1, TP_POT2, TP_POT3, TP_POT4, TP_POT5, TP_POT6
- TP_UART_TX, TP_UART_RX

---

## 3) Full Netlist by Connector/Block

## 3.1 ESP32-C6 SuperMini Header to Nets

| MCU GPIO | Net |
|:--|:--|
| 0 | POT1_WIPER |
| 1 | POT2_WIPER |
| 2 | POT3_WIPER |
| 3 | POT4_WIPER |
| 4 | POT5_WIPER |
| 6 | POT6_WIPER |
| 17 | UART_FOLLOWER_RX |
| 18 | UART_FOLLOWER_TX |

Power/header pins:
- 3V3 -> +3V3_LOGIC
- GND -> GND

## 3.2 Potentiometer Connectors (3-pin JST each)

Use 6 identical connectors (J_POT1..J_POT6), each 3 pins:
- Pin 1: POT_BUS_3V3
- Pin 2: POTx_WIPER
- Pin 3: POT_BUS_GND

Mapping:
- J_POT1 pin 2 -> POT1_WIPER
- J_POT2 pin 2 -> POT2_WIPER
- J_POT3 pin 2 -> POT3_WIPER
- J_POT4 pin 2 -> POT4_WIPER
- J_POT5 pin 2 -> POT5_WIPER
- J_POT6 pin 2 -> POT6_WIPER

## 3.3 Leader/Follower UART Connector

4-pin recommended header (H_UART1):
- Pin 1: GND
- Pin 2: UART_FOLLOWER_RX (leader TX, to follower RX)
- Pin 3: UART_FOLLOWER_TX (leader RX, from follower TX)
- Pin 4: +3V3_LOGIC (optional, only if power-sharing is required)

## 3.4 Power Input

Leader board can be powered by either:
- USB (via ESP32-C6 SuperMini onboard USB), or
- External +3V3_LOGIC input header.

If external 3.3V is provided:
- H_PWR1 pin 1: +3V3_LOGIC
- H_PWR1 pin 2: GND

Important:
- Do not apply 5V directly to +3V3_LOGIC net.
- Keep one common ground between leader, follower, and host interfaces.

---

## 4) Footprints and Package Choices

Use common KiCad library footprints where possible.

Prototype policy for this revision:
- Through-hole parts only.
- No SMD passives in this build.

## 4.1 Recommended Footprint Map

| Ref Type | Suggested Footprint |
|:--|:--|
| ESP32-C6 SuperMini socket headers | PinSocket_1x12_P2.54mm_Vertical x2 (adjust pin count to your exact SuperMini variant) |
| Pot connectors (x6) | JST_XH_B3B-XH-A_1x03_P2.50mm_Vertical |
| UART link | PinHeader_1x04_P2.54mm_Vertical |
| Optional external 3.3V power header | PinHeader_1x02_P2.54mm_Vertical |
| Test points | TestPoint_Pad_D1.5mm |
| Mount holes | MountingHole_3.2mm_M3 |
| Through-hole resistors | R_Axial_DIN0207_L6.3mm_D2.5mm_P7.62mm_Horizontal |
| Through-hole electrolytics | CP_Radial_D5.0mm_P2.00mm, CP_Radial_D6.3mm_P2.50mm |
| Through-hole ceramic caps | C_Disc_D5.0mm_W2.5mm_P5.00mm |

## 4.1.1 Devboard Header Footprints (Explicit)

ESP32-C6 SuperMini is a pluggable devboard:
- PCB footprint: PinSocket_1x12_P2.54mm_Vertical x2 (or your measured count).
- Devboard mating part: PinHeader_1x12_P2.54mm_Vertical x2 soldered on module.

If your module is not 1x12 per side:
- Keep 2.54 mm pitch and replace only pin count to match exact board.

Mechanical/orientation notes:
- Add clear silkscreen marker for pin 1.
- Keep at least 2.0 mm courtyard around socket rows.
- Lock one orientation only (no mirrored insertion).

## 4.2 Discrete Passives BOM (Through-Hole)

| RefDes | Qty | Value | Type | Voltage/Power | Net Placement |
|:--|:--:|:--|:--|:--|:--|
| C1 | 1 | 47 uF | Electrolytic radial | 10V min | +3V3_LOGIC to GND near ESP32 header |
| C2 | 1 | 100 nF | Ceramic disc THT | 25V min | +3V3_LOGIC to GND near ESP32 header |
| C3-C8 | 6 | 100 nF | Ceramic disc THT | 25V min | One from each POTx_WIPER to GND near ESP32 ADC pins |
| R1-R6 | 6 | 1 k | Axial resistor | 1/4W | Series from each pot wiper connector pin to POTx_WIPER net |
| R7-R8 | 2 | 220 ohm | Axial resistor | 1/4W | Series on UART_FOLLOWER_RX and UART_FOLLOWER_TX (optional EMI damping) |
| C9 | 1 | 10 uF | Electrolytic radial | 10V min | +3V3_LOGIC to GND near pot connector cluster |

Notes:
- R7-R8 can be DNI if UART link is short and clean.
- If ADC response is too slow, reduce C3-C8 from 100 nF to 10 nF.

## 4.3 Discrete Passives Wiring Guide

1. 3.3V rail stabilization:
- Place C1 and C2 across +3V3_LOGIC and GND near ESP32 power pins.
- Place C9 across +3V3_LOGIC and GND near pot connector fan-out.

2. Per-channel ADC conditioning:
- Route each pot wiper through series resistor R1..R6 into POTx_WIPER nets.
- Place C3..C8 from each POTx_WIPER net to GND close to ESP32 side.

3. UART conditioning:
- Place R7 in series with UART_FOLLOWER_RX near ESP32 side.
- Place R8 in series with UART_FOLLOWER_TX near ESP32 side.

---

## 5) Trace Width, Clearance, and Via Rules

For low-current leader board signals (1 oz copper):

## 5.1 Net Class Rules (Recommended)

| Net Class | Width | Clearance | Via Drill / Dia | Applies To |
|:--|:--|:--|:--|:--|
| ADC_SIGNAL | 0.25 mm (10 mil) | 0.20 mm (8 mil) | 0.30 / 0.60 mm | POTx_WIPER |
| UART_SIGNAL | 0.25 mm (10 mil) | 0.20 mm (8 mil) | 0.30 / 0.60 mm | UART_FOLLOWER_RX/TX |
| PWR_3V3 | 0.50 mm (20 mil) | 0.20 mm (8 mil) | 0.30 / 0.60 mm | +3V3_LOGIC |
| GND_RETURN | 0.80 mm (31 mil) where traced, otherwise pour | 0.20 mm (8 mil) | 0.30 / 0.60 mm | Ground returns and links |

## 5.2 Single-Layer + Jumper Strategy

- Route +3V3 and GND trunks first.
- Route six ADC channels away from UART traces where possible.
- Use wire jumpers only for unavoidable crossings.
- Stitch isolated ground-pour islands with labeled GND jumpers.

---

## 6) Spacing and Placement Rules (Practical)

- Keep ADC routing short from connectors to ESP32 pins.
- Keep pot bus traces (POT_BUS_3V3 and POT_BUS_GND) as clean shared rails.
- Place UART header near one board edge for cable access.
- Separate analog wiper traces from noisy USB/UART area when possible.

---

## 7) ERC/DRC Checklist Before Fabrication

Schematic/ERC:
- POT1..POT6 wipers map exactly to GPIO0,1,2,3,4,6.
- UART pins map exactly: TX GPIO17, RX GPIO18.
- All pot connectors use 3-pin order: 3V3, WIPER, GND.
- Through-hole package footprints are used for all passives.

PCB/DRC:
- No unrouted nets.
- No isolated copper islands left unintentionally.
- Ground continuity verified end-to-end.

Bring-up:
- Power with USB first and verify stable +3V3_LOGIC.
- Sweep each pot and confirm JOINT_STATE channel changes correctly.
- Verify UART link to follower at 115200.

---

## 8) NodeMesh/Teleop Notes for Leader Board

- This board is teleoperation input only (no motor driver stage).
- Keep board modular: ADC capture + UART transport.
- Maintain firmware-compatible GPIO mapping in section 1.

---

## 9) Schematic Symbols (What To Use)

Use connector-style symbols so net names remain firmware-readable.

Recommended symbol naming:
- U1: ESP32_C6_SUPERMINI_2x12
- J_POT1..J_POT6: JST3_POT
- H_UART1: HDR_1x04_UART
- H_PWR1: HDR_1x02_3V3

### 9.1 ESP32-C6 SuperMini Symbol (U1)

Create symbol ESP32_C6_SUPERMINI_2x12 with at least these pins exposed:

| Symbol Pin Name | MCU GPIO | Net Label |
|:--|:--|:--|
| GPIO0 | 0 | POT1_WIPER |
| GPIO1 | 1 | POT2_WIPER |
| GPIO2 | 2 | POT3_WIPER |
| GPIO3 | 3 | POT4_WIPER |
| GPIO4 | 4 | POT5_WIPER |
| GPIO6 | 6 | POT6_WIPER |
| GPIO17 | 17 | UART_FOLLOWER_RX |
| GPIO18 | 18 | UART_FOLLOWER_TX |
| 3V3 | - | +3V3_LOGIC |
| GND | - | GND |

### 9.2 Pot Connector Symbol (J_POTx)

Create symbol JST3_POT:

| Pin | Net |
|:--|:--|
| 1 | POT_BUS_3V3 |
| 2 | POTx_WIPER |
| 3 | POT_BUS_GND |

### 9.3 UART Header Symbol (H_UART1)

Create symbol HDR_1x04_UART:

| Pin | Net |
|:--|:--|
| 1 | GND |
| 2 | UART_FOLLOWER_RX |
| 3 | UART_FOLLOWER_TX |
| 4 | +3V3_LOGIC (optional) |

### 9.4 Power Header Symbol (H_PWR1)

Create symbol HDR_1x02_3V3:

| Pin | Net |
|:--|:--|
| 1 | +3V3_LOGIC |
| 2 | GND |

### 9.5 Power Symbols and Net Labels

Use global labels:
- +3V3_LOGIC
- GND
- POT_BUS_3V3
- POT_BUS_GND

---

## 10) Quick Copy Block for CAD Project Notes

Pin map summary:
- POT ADC: GPIO0,1,2,3,4,6
- UART: TX GPIO17, RX GPIO18

Prototype constraints:
- Single-layer priority.
- Through-hole only passives and connectors.
- ESP32-C6 SuperMini mounted via header sockets.

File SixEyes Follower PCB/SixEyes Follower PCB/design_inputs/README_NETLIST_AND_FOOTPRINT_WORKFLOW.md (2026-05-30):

# SixEyes Follower PCB Netlist + Footprint Workflow

This workflow uses the design package pin map and footprint policy to build the actual KiCad netlist from schematic.

## Files in this folder

- `follower_nodemesh_netlist.csv`
  - Source-of-truth connection table (RefDes, pin, net)
- `follower_nodemesh_footprint_map.csv`
  - Footprint mapping by reference pattern
- `follower_nodemesh_external.net`
  - Generated KiCad external netlist for first-pass PCB connectivity import
- `../SixEyes_Custom.pretty/WireJumper_1x02_P2.54mm.kicad_mod`
  - Custom THT wire-jumper footprint
- `../fp-lib-table`
  - Project-level footprint library table including `SixEyes_Custom`

## Important note

KiCad generates the real project netlist from the `.kicad_sch` schematic. The CSV netlist here is an implementation input, not a direct KiCad netlist replacement.

The `follower_nodemesh_external.net` file is provided for first-pass bring-up when the schematic is not finished yet.

## Step-by-step in KiCad (v8/v9/v10 style)

1. Open project: `SixEyes Follower PCB.kicad_pro`.
2. Open schematic editor for `SixEyes Follower PCB.kicad_sch`.
3. Place symbols for all blocks listed in `follower_nodemesh_netlist.csv`.
4. Wire pins and add global net labels exactly as named in the CSV.
5. Annotate schematic references.
6. Run ERC and fix all pin/net errors.
7. Open Footprint Assignment tool.
8. Apply footprints using `follower_nodemesh_footprint_map.csv`.
9. Verify custom jumper footprint resolves as `SixEyes_Custom:WireJumper_1x02_P2.54mm`.
10. Update PCB from schematic (this imports the generated netlist into PCB).
11. In PCB editor, run DRC and fix missing footprint/unconnected issues.

## Optional fast path: import external netlist now

1. Open PCB editor from `SixEyes Follower PCB.kicad_pro`.
2. Use the PCB netlist import flow and select `design_inputs/follower_nodemesh_external.net`.
3. Import as a first-pass connectivity baseline.
4. Place and route as needed, then migrate to full schematic-driven update later.

## External netlist caveats

- U1 and U2-U5 are represented with single-row socket placeholders; final module/socket dual-row realization must be finalized in schematic.
- NC pins (Jx_MOTOR pins 5 and 6) are intentionally excluded from nets.
- This netlist is for connectivity bootstrap; the long-term source of truth should still be `SixEyes Follower PCB.kicad_sch`.

## Net names that must be exact

- STEP_J1, DIR_J1, PDN_J1
- STEP_J2, DIR_J2, PDN_J2
- STEP_J3, DIR_J3, PDN_J3
- STEP_J4, DIR_J4, PDN_J4
- EN_ALL
- SERVO_WRIST_PITCH, SERVO_WRIST_YAW, SERVO_GRIPPER
- UART_LEADER_RX, UART_LEADER_TX
- SD_SCK, SD_MISO, SD_MOSI, SD_CS
- +24V_MOTOR, +6V6_SERVO, +3V3_LOGIC, GND

## Single-layer prototype reminders

- Prefer THT footprints only for this spin.
- Use jumper footprints for unavoidable crossings.
- Stitch split ground regions with explicit jumper links.
- Keep +24V and motor-current routes wide and short.

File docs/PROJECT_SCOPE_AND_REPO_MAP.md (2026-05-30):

# Project Scope And Repo Map

This document defines the authoritative scope split across the three SixEyes repositories.

## TLDR

- Use sixeyes for the standard robotic arm build (hardware + firmware) with laptop-assisted operation.
- Use nodemesh only when you want optional 4-MCU edge training/inference firmware.
- Use cyclocad only for cycloidal gear design tooling.

## Repository Ownership

### 1) sixeyes (standard package)

Repository:
- https://github.com/SixEyes-Open-Source/sixeyes

Purpose:
- The default project that most users should start with.
- Covers standard arm hardware, follower and leader firmware, ROS2/laptop workflows, assembly, validation, and deployment.

What is included:
- Main arm hardware and wiring docs.
- Standard follower and leader firmware.
- ROS2 and laptop teleoperation/control tooling.
- Hardware options that preserve future compatibility.

What is intentionally excluded:
- NodeMesh multi-node edge-perception firmware internals.
- NodeMesh camera-node firmware and ESP-NOW mesh implementation details.

Important policy:
- SD card reader hardware may be physically present for compatibility, but it is not part of default runtime behavior in the standard sixeyes flow.
- ESP32-CAM perception nodes are not part of the standard sixeyes package.

### 2) nodemesh (optional firmware overlay)

Repository:
- https://github.com/SixEyes-Open-Source/nodemesh

Purpose:
- Optional distributed firmware system for edge-first operation using 4 MCUs.

What is included:
- Node0 orchestrator firmware (control, data sync, logging, lightweight learning scaffold).
- Node1 input firmware (teleoperation stream source).
- Node2 and Node3 camera-node firmware and ESP-NOW transport.
- NodeMesh-specific docs, pinouts, checklists, and phased roadmap.

NodeMesh hardware assumptions:
- Builds on compatible SixEyes hardware foundation.
- Uses SD logging in NodeMesh mode.
- Supports low-cost ESP32-CAM based perception nodes (and can be adapted to S3 camera variants when needed).

### 3) cyclocad (mechanical design tool)

Repository:
- https://github.com/SixEyes-Open-Source/cyclocad

Purpose:
- Cycloidal gear generation and CAD export tooling.

What is included:
- Gear profile generation scripts.
- DXF and CSV export artifacts.
- SolidWorks macro and related docs.

## Folder To Repo Routing (Current)

From the workspace root:

- nodemesh/ → nodemesh repository
- cyclocad/ → cyclocad repository
- firmware/, ros2_ws/, tools/, simulation/, hardware_assets/, SixEyes Follower PCB/, docs/, README.md, CONTRIBUTING.md, LICENSE → sixeyes repository

> **Note**: The `sixeyes/` wrapper folder has been removed. All SixEyes project code now lives directly at the repository root.  
> If you cloned before June 2026 and had paths like `sixeyes/firmware/...`, update them to `firmware/...`.

## Documentation Simplification Rules

Use these rules to keep docs understandable and avoid overlap:

1. One authoritative page per topic.
- Keep one source-of-truth doc for each of: pinout, wiring, flashing, protocol, test plan.

2. Turn duplicates into pointers.
- If a doc repeats material from the authoritative page, replace duplicated sections with a short summary and a direct link.

3. Keep repo boundaries explicit at the top of entry docs.
- Every root README should state what the repo is for and what it is not for.

4. Keep standard and optional paths separate.
- Standard sixeyes flow should not require NodeMesh docs.
- NodeMesh docs can reference sixeyes hardware baseline, but should not redefine sixeyes standards unless required.

5. Archive instead of deleting first.
- For uncertain duplicate docs, move to an archive folder before permanent deletion.

## Recommended Next Cleanup Pass

- In sixeyes: keep only one primary hardware bring-up path and one protocol source-of-truth.
- In nodemesh: keep one architecture overview plus one implementation checklist; convert extra long-form narrative docs into concise reference pages.
- In both repos: add a short "Read this first" section at top-level docs index with no more than 3 starting links.

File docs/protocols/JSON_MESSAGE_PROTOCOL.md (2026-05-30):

# JSON Message Protocol for SixEyes UART Communication

Working reference for the extensible JSON message protocol used in SixEyes firmware for UART-based communication with ROS2 and external systems.

---

## Table of Contents

1. [Protocol Overview](#protocol-overview)
2. [Message Format](#message-format)
3. [Message Types](#message-types)
4. [Command Messages (ROS2 → ESP32)](#command-messages-ros2--esp32)
5. [Response Messages (ESP32 → ROS2)](#response-messages-esp32--ros2)
6. [Error Handling](#error-handling)
7. [Integration Examples](#integration-examples)
8. [Performance & Constraints](#performance--constraints)
9. [Backward Compatibility](#backward-compatibility)

---

## Protocol Overview

### Design Goals

✅ **Extensible**: New message types without breaking existing code
✅ **Human-Readable**: JSON format for debugging in terminal
✅ **Non-Blocking**: Parser never stalls the control loop
✅ **Type-Safe**: C++ polymorphism for message handling
✅ **Efficient**: Minimal RAM overhead (~512 bytes buffer)
✅ **Flexible**: Optional fields for future additions

### Transport Layer

| Property | Value |
|:---|:---|
| **Port** | USB CDC (Virtual Serial) or UART2 |
| **Baud Rate** | 115200 bps |
| **Frame Format** | Line-delimited JSON (newline = `\n`) |
| **Encoding** | UTF-8 (ASCII compatible) |
| **Max Message Size** | 512 bytes (configurable) |
| **Duplex** | Full duplex (RX and TX simultaneous) |

---

## Message Format

### Basic Structure

```json
{
  "cmd": "MESSAGE_TYPE",
  "seq": 42,
  "ts": 1000500,
  ... type-specific fields ...
}
```

### Common Fields

| Field | Type | Required | Description |
|:---|:-----|:---|:---|
| `cmd` | string | ✓ Required | Message type identifier (e.g., "MOTOR_TARGET") |
| `seq` | uint32 | Optional | Sequence number for ack/tracking |
| `ts` | uint64 | Optional | Timestamp in milliseconds (firmware fills if omitted) |

### Field Types in JSON

```
Integer:  "count": 42
Float:    "value": 3.14
Boolean:  "enable": true
String:   "name": "Motor0"
Array:    "targets": [1.0, 2.0, 3.0, 4.0]
Object:   "config": {"param1": 1.0, "param2": 2.0}
```

---

## Message Types

### Command Message Types (implemented + planned)

| Type | Direction | Purpose | Status |
|:-----|:---|:---|:---|
| `MOTOR_TARGET` | ROS2 → ESP32 | Set stepper motor target positions | ✅ Implemented |
| `SERVO_TARGET` | ROS2 → ESP32 | Set servo PWM values | ✅ Implemented |
| `ENABLE_MOTORS` | ROS2 → ESP32 | Enable/disable motor outputs | ✅ Implemented |
| `RESET_FAULT` | ROS2 → ESP32 | Clear fault state | ✅ Implemented |
| `HOME_ZERO` | ROS2/Laptop → ESP32 | Software zeroing (current pose as logical zero) | ✅ Implemented |
| `HOME_STALLGUARD` | ROS2/Laptop → ESP32 | Hybrid StallGuard homing (seek stall, backoff, re-approach) | ✅ Implemented |
| `JOINT_STATE` | Leader ESP32 → Follower/Laptop | Stream leader arm joint angles (teleoperation) | ✅ Implemented |
| `TUNE_PID` | ROS2 → ESP32 | Update PID gains | ✅ Implemented |
| `CONFIG_PARAM` | ROS2 → ESP32 | Set configuration parameter | ✅ Implemented |
| `CONFIG_SAVE` | ROS2 → ESP32 | Save config to EEPROM | 🔲 Planned |
| `CONFIG_RESET` | ROS2 → ESP32 | Reset to defaults | 🔲 Planned |
| `TELEMETRY_ENABLE` | ROS2 → ESP32 | Enable/disable telemetry | ✅ Implemented |
| `TELEMETRY_RATE` | ROS2 → ESP32 | Set telemetry rate (Hz) | ✅ Implemented |
| `HEARTBEAT` | ROS2 → ESP32 | Keep-alive signal | ✅ Implemented |

### Response Message Types (11 types)

| Type | Direction | Purpose | Status |
|:-----|:---|:---|:---|
| `MOTOR_STATUS` | ESP32 → ROS2 | Current motor state | ✅ Implemented |
| `SERVO_STATUS` | ESP32 → ROS2 | Current servo state | ✅ Implemented |
| `SYSTEM_STATUS` | ESP32 → ROS2 | Overall system health | ✅ Implemented |
| `FAULT_DETAILS` | ESP32 → ROS2 | Detailed fault info | ✅ Implemented |
| `STATISTICS` | ESP32 → ROS2 | Runtime statistics | ✅ Implemented |
| `STATUS_HEARTBEAT` | ESP32 → ROS2 | Status keep-alive | ✅ Implemented |

### Teleoperation Streaming Messages (Phase 2)

| Type | Direction | Purpose | Status |
|:-----|:---|:---|:---|
| `JOINT_STATE` | Leader ESP32 → Laptop/Follower | Stream leader joint angles + valid mask | ✅ Implemented in `leader_esp32` |
| `TELEMETRY_STATE` | Follower ESP32 → Laptop/Leader | Stream real follower feedback for sync/analysis | ✅ Implemented in `follower_esp32` |

---

## Teleoperation Streaming Messages (Phase 2)

These messages are used for the teleoperation pipeline and data collection flow.

### JOINT_STATE - Leader Joint Streaming

**Purpose**: Publish leader-arm joint angles continuously for mirroring.

**Source**: `sixeyes/firmware/leader_esp32`.

**Nominal rate**: 100 Hz (every 10 ms).

**Format**:
```json
{
  "cmd": "JOINT_STATE",
  "seq": 42,
  "ts": 1000500,
  "leader_joints": [0.0, 45.0, 90.0, 135.0, 90.0, 90.0],
  "valid_mask": [1, 1, 1, 1, 1, 1]
}
```

**Fields**:
| Field | Type | Description |
|:---|:-----|:---|
| `leader_joints` | float[6] | Leader joint angles (degrees) |
| `valid_mask` | uint8[6] | Per-joint validity (`1` valid, `0` invalid/disconnected) |

### Leader Local Calibration Commands (USB-CDC)

These commands are consumed by `leader_esp32` over its own USB serial console and are used to set potentiometer home/zero before teleoperation runs.

| Command | Accepted Forms | Effect |
|:---|:---|:---|
| `HOME_ZERO` | `HOME_ZERO` or `{"cmd":"HOME_ZERO"}` | Captures current pot pose as the zero offset |
| `CAPTURE_ZERO` | `CAPTURE_ZERO` or `{"cmd":"CAPTURE_ZERO"}` | Alias for zero capture (same behavior as `HOME_ZERO`) |

Notes:
- Offsets are applied to outgoing `JOINT_STATE.leader_joints`.
- Offsets are runtime-only (reboot clears them).
- Success log line: `[CAL] Leader pot zero captured from current pose`.

### TELEMETRY_STATE - Follower Telemetry Streaming

**Purpose**: Return follower state during teleoperation (for sync, logging, model training).

**Status**: Implemented in follower teleoperation pipeline.

**Current format**:
```json
{
  "cmd": "TELEMETRY_STATE",
  "seq": 42,
  "ts": 1000500,
  "follower_joints": [0.0, 45.0, 89.5, 134.2, 90.0, 91.2],
  "follower_joint_velocities": [3.1, 5.4, 4.8, 0.0, 0.0, 0.0],
  "errors": [0.0, 0.2, 0.5, 0.8, 0.0, 1.2],
  "faults": [0, 0, 0, 0, 0, 0],
  "valid_mask": [1, 1, 1, 1, 1, 1],
  "motor_positions_deg": [0.0, 1125.0, -1125.0, 2240.0],
  "motor_velocities_deg_s": [80.0, 92.0, -92.0, 77.0],
  "motor_errors_deg": [1.0, -2.0, 2.0, 1.5],
  "motor_currents_ma": [850, 900, 900, 870],
  "motors_en": 1,
  "fault_code": 0,
  "homing": 0,
  "telemetry_rate_hz": 100
}
```

**Fields**:
| Field | Type | Description |
|:---|:-----|:---|
| `follower_joints` | float[6] | Follower joint state in teleoperation joint space (base, shoulder, elbow, wrist pitch, wrist yaw, gripper) |
| `follower_joint_velocities` | float[6] | Estimated joint velocities in teleoperation joint space (deg/s) |
| `errors` | float[6] | Leader-minus-follower joint error (deg) for each teleop joint |
| `faults` | uint8[6] | Per-joint fault indicator (global/system + input validity aware) |
| `valid_mask` | uint8[6] | Echo of most recent leader validity mask (`1` valid, `0` invalid) |
| `motor_positions_deg` | float[4] | Raw stepper motor shaft positions (deg) |
| `motor_velocities_deg_s` | float[4] | Raw stepper motor shaft velocities (deg/s) |
| `motor_errors_deg` | float[4] | Raw motor target-tracking errors (deg) |
| `motor_currents_ma` | uint16[4] | Configured/diagnostic current values from TMC2209 driver path |
| `motors_en` | uint8 | Motor enable state (`1` enabled, `0` disabled) |
| `fault_code` | uint32 | Current fault code from `FaultManager` |
| `homing` | uint8 | Homing state (`1` active, `0` idle) |
| `telemetry_rate_hz` | uint16 | Active telemetry stream rate |

**Emission behavior**:
- Emitted immediately after valid `JOINT_STATE` commands.
- Also emitted periodically from control loop at configured rate.
- Controlled by `TELEMETRY_ENABLE` and `TELEMETRY_RATE` commands.

---

## Command Messages (ROS2 → ESP32)

### 1. MOTOR_TARGET - Set Stepper Positions

**Purpose**: Command stepper motors to absolute positions

**Format**:
```json
{
  "cmd": "MOTOR_TARGET",
  "seq": 1,
  "targets": [0.0, 45.0, 90.0, 135.0]
}
```

**Fields**:
| Field | Type | Range | Description |
|:---|:-----|:---|:---|
| `targets` | float[] | 0-360 deg | Absolute positions for each motor (degrees) |

**Constraints**:
- Maximum 4 values (NUM_STEPPERS)
- All motors updated atomically
- Values beyond 0-360 wrap around

**Response**:
ESP32 will execute motion and send `MOTOR_STATUS` at telemetry rate.

**Example**: Move all motors to safe position
```bash
echo '{"cmd":"MOTOR_TARGET","seq":1,"targets":[90.0,90.0,90.0,90.0]}' > /dev/ttyUSB0
```

---

### 2. SERVO_TARGET - Set Servo PWM

**Purpose**: Command servo motors to specific PWM or degrees

**Format (PWM microseconds)**:
```json
{
  "cmd": "SERVO_TARGET",
  "seq": 2,
  "pwm_us": [1500, 1400, 1600]
}
```

**Format (Degrees)**:
```json
{
  "cmd": "SERVO_TARGET",
  "seq": 2,
  "degrees": [90, 80, 100]
}
```

**Fields**:
| Field | Type | Range | Description |
|:---|:-----|:---|:---|
| `pwm_us` (alt) | float[] | 1000-2000 µs | PWM pulse width in microseconds |
| `degrees` (alt) | float[] | 0-180 deg | Servo position in degrees |

**Constraints**:
- Use either `pwm_us` OR `degrees`, not both
- Default range: 1000-2000 µs (standard servo)
- 1500 µs = 90° (neutral)

**Conversion**:
- 0° → 1000 µs (full counter-clockwise)
- 90° → 1500 µs (neutral)
- 180° → 2000 µs (full clockwise)

**Example**: Open gripper (0°)
```bash
echo '{"cmd":"SERVO_TARGET","seq":2,"degrees":[0,90,90]}' > /dev/ttyUSB0
```

---

### 3. ENABLE_MOTORS - Control Motor Power

**Purpose**: Enable or disable all motor outputs

**Format**:
```json
{
  "cmd": "ENABLE_MOTORS",
  "seq": 3,
  "enable": true
}
```

**Fields**:
| Field | Type | Description |
|:---|:-----|:---|
| `enable` | bool | true=enable, false=disable |

**Safety Notes**:
- Disabling immediately sets EN pin LOW
- Motors freewheel when disabled
- Does NOT affect current faults
- Requires explicit RESET_FAULT to recover

**Example**: Disable motors for safety
```bash
echo '{"cmd":"ENABLE_MOTORS","seq":3,"enable":false}' > /dev/ttyUSB0
```

---

### 4. RESET_FAULT - Clear Fault State

**Purpose**: Acknowledge fault and attempt recovery

**Format**:
```json
{
  "cmd": "RESET_FAULT",
  "seq": 4,
  "ack": true
}
```

**Fields**:
| Field | Type | Description |
|:---|:-----|:---|
| `ack` | bool (optional) | Acknowledgment flag (default: false) |

**Behavior**:
1. Clears latched fault bits
2. Re-enables motors if safe
3. Logs fault details for debugging

**Example**: Clear fault after thermal shutdown
```bash
echo '{"cmd":"RESET_FAULT","seq":4}' > /dev/ttyUSB0
```

---

### 5. TUNE_PID - Update PID Gains

**Purpose**: Dynamically adjust motor PID controller parameters

**Format**:
```json
{
  "cmd": "TUNE_PID",
  "seq": 5,
  "motor": 0,
  "kp": 2.5,
  "ki": 0.1,
  "kd": 0.2,
  "antiwindup": true
}
```

**Fields**:
| Field | Type | Default | Description |
|:---|:-----|:---|:---|
| `motor` | uint8 | 0 | Motor index (0-3) |
| `kp` | float | 2.0 | Proportional gain |
| `ki` | float | 0.05 | Integral gain |
| `kd` | float | 0.1 | Derivative gain |
| `antiwindup` | bool | true | Enable anti-windup |

**Tuning Guidelines**:
- **High Kp**: Fast response, but may oscillate
- **High Ki**: Eliminates steady-state error, but slow response
- **High Kd**: Damping, but noise-sensitive
- **Start with**: Kp=2.0, Ki=0.05, Kd=0.1

**Example**: Increase responsiveness
```bash
echo '{"cmd":"TUNE_PID","seq":5,"motor":0,"kp":3.0,"ki":0.08,"kd":0.15}' > /dev/ttyUSB0
```

---

### 4a. HOME_ZERO - Latch Current Position as Zero

**Purpose**: Define current stepper positions as logical joint zero.

**Format**:
```json
{
  "cmd": "HOME_ZERO",
  "seq": 40
}
```

**Behavior**:
1. Latches each motor's current position as zero offset
2. Resets target/current logical joint deltas around new zero frame
3. Keeps safety and fault state unchanged

**Example**:
```bash
echo '{"cmd":"HOME_ZERO","seq":40}' > /dev/ttyUSB0
```

---

### 4b. HOME_STALLGUARD - Hybrid Mechanical + Logical Homing

**Purpose**: Execute coarse mechanical reference via StallGuard, then align logical zero.

**Format**:
```json
{
  "cmd": "HOME_STALLGUARD",
  "seq": 41
}
```

**Behavior**:
1. Enables StallGuard check on configured axes
2. Seeks stall in homing direction
3. Backs off and re-approaches for repeatability
4. Stores the homed position as logical zero offset

**Example**:
```bash
echo '{"cmd":"HOME_STALLGUARD","seq":41}' > /dev/ttyUSB0
```

---

### 6. CONFIG_PARAM - Set Configuration Parameter

**Purpose**: Modify firmware configuration parameters

**Format**:
```json
{
  "cmd": "CONFIG_PARAM",
  "seq": 6,
  "param": "MAX_MOTOR_SPEED",
  "value": 300.0
}
```

**Available Parameters**:
| Parameter | Type | Default | Description |
|:---|:-----|:---|:---|
| `MAX_MOTOR_SPEED` | float | 360.0 | Max motor speed (deg/s) |
| `MAX_SERVO_SPEED` | float | 60.0 | Max servo speed (deg/s) |
| `HEARTBEAT_TIMEOUT_MS` | uint32 | 500 | ROS2 heartbeat timeout |
| `MOTOR_CURRENT_LIMIT_MA` | float | 1500.0 | Stepper current limit |

**Example**: Reduce max motor speed for safety
```bash
echo '{"cmd":"CONFIG_PARAM","seq":6,"param":"MAX_MOTOR_SPEED","value":180.0}' > /dev/ttyUSB0
```

---

### 7. TELEMETRY_ENABLE - Enable/Disable Telemetry Stream

**Purpose**: Control whether ESP32 sends unsolicited status updates

**Format**:
```json
{
  "cmd": "TELEMETRY_ENABLE",
  "seq": 7,
  "enable": true
}
```

**Behavior**:
- When enabled: ESP32 sends `STATUS_HEARTBEAT` at configured rate
- When disabled: Only send responses to queries
- Default: Enabled after startup

**Example**: Stop telemetry for bandwidth testing
```bash
echo '{"cmd":"TELEMETRY_ENABLE","seq":7,"enable":false}' > /dev/ttyUSB0
```

---

### 8. TELEMETRY_RATE - Set Telemetry Update Rate

**Purpose**: Change how often ESP32 broadcasts status

**Format**:
```json
{
  "cmd": "TELEMETRY_RATE",
  "seq": 8,
  "hz": 10
}
```

**Fields**:
| Field | Type | Range | Default | Description |
|:---|:-----|:---|:---|:---|
| `hz` | uint16 | 1-100 | 10 | Update frequency in Hz |

**Constraints**:
- Control loop runs at 400 Hz
- Telemetry rate should be ≤ 100 Hz
- Each packet is ~200 bytes
- At 100 Hz: ~20 KB/s bandwidth

**Example**: Increase telemetry rate for diagnostics
```bash
echo '{"cmd":"TELEMETRY_RATE","seq":8,"hz":50}' > /dev/ttyUSB0
```

---

### 9. HEARTBEAT - Keep-Alive Signal (JSON Version)

**Purpose**: Tell ESP32 that ROS2 is still alive

**Format**:
```json
{
  "cmd": "HEARTBEAT",
  "seq": 123
}
```

**Behavior**:
- Updates ROS2 heartbeat timer (prevents motor disable)
- Response: `STATUS_HEARTBEAT` sent at next telemetry interval
- Default rate from ROS2: ≥50 Hz

**Note**: ASCII version (`HB:0,N\n`) still supported for backward compatibility.

**Example**: Send heartbeat at 50 Hz
```bash
while true; do
  echo '{"cmd":"HEARTBEAT","seq":'$(( $(date +%s%N) / 1000000 ))'}' > /dev/ttyUSB0
  sleep 0.02  # 50 Hz = 20 ms
done
```

---

## Response Messages (ESP32 → ROS2)

All response messages are unsolicited updates sent at the configured telemetry rate, unless otherwise noted.

### 1. MOTOR_STATUS - Motor State Update

**Format**:
```json
{
  "cmd": "MOTOR_STATUS",
  "seq": 100,
  "motor": 0,
  "pos": 45.23,
  "vel": 12.5,
  "current": 1.2,
  "temp": 42.0,
  "state": 0
}
```

**Fields**:
| Field | Type | Unit | Description |
|:---|:-----|:-----|:---|
| `motor` | uint8 | - | Motor index (0-3) |
| `pos` | float | deg | Current position |
| `vel` | float | deg/s | Current velocity |
| `current` | float | mA | Motor current draw |
| `temp` | float | °C | Driver temperature |
| `state` | uint8 | - | 0=idle, 1=moving, 2=fault |

**Frequency**: Sent at telemetry rate for each motor (one msg per motor per update)

---

### 2. SERVO_STATUS - Servo State Update

**Format**:
```json
{
  "cmd": "SERVO_STATUS",
  "seq": 101,
  "servo": 0,
  "pwm_us": 1500,
  "current": 250,
  "temp": 35.0,
  "state": 0
}
```

**Fields**:
| Field | Type | Unit | Description |
|:---|:-----|:-----|:---|
| `servo` | uint8 | - | Servo index (0-2) |
| `pwm_us` | float | µs | Current PWM pulse width |
| `current` | float | mA | Servo current |
| `temp` | float | °C | Estimated temperature |
| `state` | uint8 | - | 0=idle, 1=moving, 2=error |

---

### 3. SYSTEM_STATUS - Overall Health Report

**Format**:
```json
{
  "cmd": "SYSTEM_STATUS",
  "seq": 102,
  "uptime_ms": 12345600,
  "heap_free": 65536,
  "heap_total": 327680,
  "core0_cpu": 25.3,
  "core1_cpu": 5.2,
  "fault_count": 0,
  "motors_en": 1,
  "ros2_alive": 1
}
```

**Fields**:
| Field | Type | Unit | Description |
|:---|:-----|:-----|:---|
| `uptime_ms` | uint32 | ms | System uptime since boot |
| `heap_free` | uint32 | bytes | Available heap memory |
| `heap_total` | uint32 | bytes | Total heap memory |
| `core0_cpu` | float | % | Core 0 CPU utilization |
| `core1_cpu` | float | % | Core 1 CPU utilization |
| `fault_count` | uint8 | - | Number of faults occurred |
| `motors_en` | bool | - | Motor outputs enabled |
| `ros2_alive` | bool | - | ROS2 heartbeat received |

---

### 4. FAULT_DETAILS - Fault Information

**Format**:
```json
{
  "cmd": "FAULT_DETAILS",
  "seq": 103,
  "fault_code": 0x0001,
  "description": "Motor 0 overcurrent",
  "timestamp_ms": 12345600,
  "severity": 2,
  "is_latched": true
}
```

**Fault Codes**:
| Code | Name | Severity | Description |
|:-----|:-----|:---|:---|
| 0x0001 | MOTOR_OVERCURRENT | HIGH | Motor current exceeded limit |
| 0x0002 | THERMAL_FAULT | HIGH | Driver overtemperature |
| 0x0004 | STALL_DETECTED | MEDIUM | Stepper stall detected |
| 0x0008 | HEARTBEAT_TIMEOUT | HIGH | ROS2 heartbeat lost |
| 0x0010 | UART_ERROR | LOW | Communication error |

---

### 5. STATUS_HEARTBEAT - Keep-Alive Response

**Format**:
```json
{
  "cmd": "STATUS_HEARTBEAT",
  "seq": 200,
  "fault": 0,
  "motors_en": 1,
  "ros2_alive": 1,
  "freq": 400.2
}
```

**Fields**:
| Field | Type | Description |
|:---|:-----|:---|
| `fault` | uint8 | Fault present flag (0=no fault, 1=fault) |
| `motors_en` | uint8 | Motors enabled (0=disabled, 1=enabled) |
| `ros2_alive` | uint8 | ROS2 heartbeat received (0=timeout, 1=alive) |
| `freq` | float | Measured control loop frequency |

**Purpose**: Compact status update sent at telemetry rate

---

## Error Handling

### Parse Errors

If the ESP32 cannot parse a message, it responds with error details:

```json
{
  "error": "Missing required field: cmd",
  "line": 42,
  "timestamp_ms": 12345600
}
```

**Common Errors**:
| Error | Cause | Solution |
|:---|:---|:---|
| `Missing required field: cmd` | No "cmd" field in JSON | Add "cmd" field |
| `Unknown command type: TYPO` | Wrong message type name | Check spelling |
| `RX buffer overflow` | Message too long | Split into smaller messages |
| `Handler table full` | Too many handlers registered | Unregister unused handlers |

### Message Validation

```
INPUT: "{"cmd":"MOTOR_TARGET"}\n"    (missing "targets")
OUTPUT: [Error logged, message dropped]

INPUT: "{"cmd":"SERVO_TARGET","degrees":[1,2]}\n"
OUTPUT: Processed successfully (2 servos updated, 3rd unchanged)
```

---

## Integration Examples

### Example 1: Basic Motor Control Loop (Python/ROS2)

```python
#!/usr/bin/env python3
import serial
import json
import time

# Connect to ESP32
ser = serial.Serial('/dev/ttyUSB0', 115200, timeout=1)

# Send motor targets
motor_targets = [0.0, 45.0, 90.0, 135.0]
msg = {
    "cmd": "MOTOR_TARGET",
    "seq": 1,
    "targets": motor_targets
}
ser.write((json.dumps(msg) + '\n').encode())

# Wait for response
time.sleep(0.5)
while ser.in_waiting:
    response = ser.readline().decode().strip()
    data = json.loads(response)
    print(f"Motor {data['motor']}: pos={data['pos']:.2f}°, current={data['current']:.2f} mA")
```

### Example 2: PID Tuning (Bash)

```bash
#!/bin/bash
# Tune Motor 0 for faster response

echo "Current gains..."
echo '{"cmd":"TUNE_PID","seq":1,"motor":0,"kp":2.0,"ki":0.05,"kd":0.1}' > /dev/ttyUSB0
sleep 0.1

echo "Increased Kp..."
echo '{"cmd":"TUNE_PID","seq":2,"motor":0,"kp":3.0,"ki":0.05,"kd":0.1}' > /dev/ttyUSB0
sleep 1

echo "Check for oscillation..."
# Read 20 motor status updates
for i in {1..20}; do
  read -t 0.1 status < /dev/ttyUSB0
  echo "$status" | grep MOTOR_STATUS && echo "$status" | jq '.pos'
done
```

### Example 3: Fault Recovery (C++)

```cpp
#include <serial/serial.h>
#include <ArduinoJson.h>

serial::Serial ser("/dev/ttyUSB0", 115200);

void handleFaultRecovery() {
    // 1. Disable motors (safe state)
    StaticJsonDocument<256> disable_msg;
    disable_msg["cmd"] = "ENABLE_MOTORS";
    disable_msg["seq"] = 10;
    disable_msg["enable"] = false;
    
    String output;
    serializeJson(disable_msg, output);
    ser.write(output + "\n");
    
    // 2. Wait for fault to clear
    delay(2000);
    
    // 3. Reset fault
    StaticJsonDocument<256> reset_msg;
    reset_msg["cmd"] = "RESET_FAULT";
    reset_msg["seq"] = 11;
    
    serializeJson(reset_msg, output);
    ser.write(output + "\n");
    
    // 4. Re-enable motors
    disable_msg["enable"] = true;
    disable_msg["seq"] = 12;
    serializeJson(disable_msg, output);
    ser.write(output + "\n");
}
```

### Example 4: Teleoperation Bridge (Leader → Follower)

```bash
cd sixeyes/tools
python teleoperation_bridge.py --leader-port COM5 --follower-port COM6 --log-file teleop_session.jsonl
```

Behavior:
- Reads line-delimited JSON from leader serial.
- Forwards validated `JOINT_STATE` payloads to follower serial.
- Receives `TELEMETRY_STATE` from follower in parallel (joint + motor feedback payload).
- Drops malformed packets and tracks counters.
- Optionally writes both directions to JSONL for dataset collection.

### Example 5: Operator Command Sequence (Python Helper)

```bash
cd sixeyes/tools
python operator_control.py --port COM6 teleop-ready
python operator_control.py --port COM6 home
python operator_control.py --port COM6 stallguard-home
```

Behavior:
- Sends heartbeat and safety-aware command sequence
- Enables motors and supports fault reset flow
- Triggers software zero or StallGuard hybrid homing

---

## Performance & Constraints

### Bandwidth

| Metric | Value |
|:---|:---|
| Baud Rate | 115200 bps |
| Bytes per Bit | ~87 µs |
| Average Message Size | 150-300 bytes |
| Max Message Rate | ~100-300 messages/sec (without saturation) |
| Typical Telemetry @ 10 Hz | ~1.5-3 KB/sec |

### Latency

| Operation | Latency | Notes |
|:---|:---|:---|
| Parse + Dispatch | < 1 ms | Depends on JSON complexity |
| Motor Response | 2.5 ms | Next control loop execution |
| Servo Response | 2.5 ms | Next control loop execution |
| Status Telemetry | 100 ms | At 10 Hz default rate |

### Memory

```
RX Buffer:              512 bytes (configurable)
JSON Document:          512 bytes (stack-allocated per message)
Handler Table:          ~100 bytes (16 max handlers)
─────────────────────────────────
Total Overhead:         ~1.1 KB
Available After Parsing: 319 KB (of 320 KB total)
```

---

## Backward Compatibility

### ASCII Heartbeat Support

The firmware continues to support the original ASCII heartbeat protocol:

```
ASCII (Still Supported):     HB:0,42\n
JSON (New Alternative):      {"cmd":"HEARTBEAT","seq":42}\n
```

Both formats are accepted and equivalent. Mixing them in the same stream is safe.

### Migration Path

1. **Phase 1** (Current): ASCII heartbeats work, JSON optional
2. **Phase 2** (v1.1.0): Both protocols supported equally
3. **Phase 3** (v2.0.0): JSON preferred, ASCII deprecated (but still work)

### Coexistence

```
ROS2 → ESP32:
  50 Hz ASCII heartbeats   (HB:0,N)
  + occasional JSON cmds   ({"cmd":"TUNE_PID",...})

ESP32 → ROS2:
  Status heartbeats        (SB:f,e,r ASCII)
  + JSON telemetry         (STATUS_HEARTBEAT JSON)
```

---

## Extensions & Future Work

### Planned Message Types

- **CONFIG_SAVE / CONFIG_RESET**: EEPROM management
- **MOTOR_VELOCITY_TARGET**: Direct velocity commands
- **ADVANCED_PID**: Gain scheduling, feed-forward
- **TRAJECTORY_PLANNING**: Multi-point motion profiles
- **VISION_FEEDBACK**: Camera integration messages
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

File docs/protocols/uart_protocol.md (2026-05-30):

# UART Protocol (canonical)

This file is the canonical UART protocol sketch for Leader → Follower absolute joint target messages.

Design constraints (must be followed):
- Only absolute joint targets allowed (no delta commands).
- Include sequence number and CRC32 for integrity.
- Heartbeat is a short, frequent packet; heartbeat timeout is ~500 ms.
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

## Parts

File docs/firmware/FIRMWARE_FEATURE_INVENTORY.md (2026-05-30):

# SixEyes Firmware Documentation Checklist

Track firmware documentation completion with explicit owner, status, and priority.

## Scope

- Follower firmware: `firmware/follower_esp32`
- Leader firmware: `firmware/leader_esp32`
- Teleoperation bridge: `tools/teleoperation_bridge.py`

## Status Legend

- `todo` = not documented yet
- `in-progress` = partial docs exist, needs refinement
- `done` = documented and reviewed

## Checklist Table

| ID | Feature Area | What to Document | Owner | Priority | Status | Primary Source | Notes |
|:---|:---|:---|:---|:---|:---|:---|:---|
| FW-001 | Mode Selection | `OPERATION_MODE` usage and defaults | Vincent | P0 | in-progress | `modules/config/mode_config.h` | Ensure examples for mode 1/2 are consistent in all docs |
| FW-002 | Mode Router | MessageRouter init + route behavior | Vincent | P1 | done | `modules/comms/message_router.*` | UartJsonParser.init() called here; both modes wired |
| FW-003 | JSON Parser Core | Non-blocking parse model and buffer limits | Vincent | P0 | done | `modules/comms/uart_json_parser/*` | parser.init() + parser.update() now called each control loop tick |
| FW-004 | JSON Message Types | Full command/response matrix | Vincent | P0 | done | `uart_json_messages.h` | JOINT_STATE (type 8) added; all teleop commands present |
| FW-005 | VLA Command Path | MOTOR/SERVO/ENABLE command handling | Vincent | P1 | in-progress | `modes/vla_inference/*` | Handlers registered; handleCommand() stub remains |
| FW-006 | Teleop JOINT_STATE | Joint mapping + valid_mask semantics | Vincent | P0 | done | `modes/teleoperation/teleoperation_handler.cpp` | UartJsonParser callback wired; 6-joint → 4-motor + 3-servo mapping complete |
| FW-007 | TELEMETRY_STATE Payload | Output fields and update rate | Vincent | P0 | done | `teleoperation_handler.cpp` | Full 6-joint + 4-motor telemetry; rate configurable via TELEMETRY_RATE |
| FW-008 | SafetyTask Logic | Enable/disable gate and fault interactions | Vincent | P0 | done | `modules/safety/safety_task.*` | isSafeToOperate() checks heartbeat + ROS2 alive; bitmask faults |
| FW-009 | Heartbeat RX | `HB:source,seq` parser details | Vincent | P1 | in-progress | `modules/safety/heartbeat_receiver.*` | Add packet examples and edge cases |
| FW-010 | Heartbeat TX | `SB:fault,motors_en,ros2_alive` timing | Vincent | P1 | in-progress | `modules/safety/heartbeat_transmitter.*` | Mention packet drop behavior when busy |
| FW-011 | Fault Manager | Latch/clear fault lifecycle | Vincent | P1 | done | `modules/safety/fault_manager.*` | Upgraded to uint32 bitmask; clearFault(f) method added; multiple simultaneous faults supported |
| FW-012 | Motor Controller | PID/interpolation/diagnostics interfaces | Vincent | P0 | in-progress | `modules/motor_control/motor_controller.*` | Add tuning defaults and constraints |
| FW-013 | Servo Manager | Degrees/PWM API and watchdog behavior | Vincent | P0 | in-progress | `modules/servo_control/servo_manager.*` | Include clamp ranges and startup posture |
| FW-014 | Control Scheduler | 500 Hz loop order and timing stats | Vincent | P0 | done | `modules/motor_control/motor_control_scheduler.*` | vTaskDelayUntil enforces 500 Hz; UartJsonParser.update() added to loop |
| FW-015 | TMC2209 Driver | Driver init and communication model | Vincent | P1 | todo | `modules/drivers/tmc2209/*` | Add practical wiring + config notes |
| FW-016 | HAL Layer | GPIO/ADC abstraction contracts | Vincent | P2 | todo | `modules/hal/*` | Keep concise unless APIs expand |
| FW-017 | Telemetry Formatter | Basic/joint payload formatter usage | Vincent | P2 | todo | `modules/telemetry/telemetry_formatter.*` | Add sample payloads |
| FW-018 | Logging Utility | log levels and formatting helpers | Vincent | P2 | done | `modules/util/logging.h` | debug/debugf now gated by SIXEYES_DEBUG; no heap alloc in release builds |
| FW-019 | Leader Streamer | ADC sampling and JOINT_STATE generation | Vincent | P0 | done | `leader_esp32/src/main.cpp` | 8-sample ADC averaging; boot-hold until zero captured; 100 Hz publish |
| FW-020 | Bridge Forwarding | Leader->Follower forwarding pipeline | Vincent | P0 | in-progress | `tools/teleoperation_bridge.py` | Include startup order and failure modes |
| FW-021 | Bridge Telemetry Intake | Follower telemetry handling/logging | Vincent | P1 | in-progress | `tools/teleoperation_bridge.py` | Clarify direction labels in JSONL |
| FW-022 | Bridge Stream Metrics | Gaps, out-of-order, latency, jitter definitions | Vincent | P0 | in-progress | `tools/teleoperation_bridge.py` | Add interpretation thresholds in docs |
| FW-023 | ROS2 Teleop Integration | End-to-end ROS2 runtime path for teleop | Vincent | P0 | done | `ros2_ws/src/*` | 4 of 5 nodes fully implemented: usb_bridge_node, safety_node, camera_node, joint_state_node; vla_inference_node stub remains |
| FW-024 | E2E Teleop Testing | Test plan for leader->bridge->follower | Vincent | P0 | todo | `docs/testing`, `tools` | Add automated regression script |

## Immediate Documentation Sprint (Suggested)

1. Close all `P0` rows to `done`
2. Convert `in-progress` sections into protocol + architecture diagrams
3. Add one reproducible test case per `P0` feature
4. Review all references to mode selection (`OPERATION_MODE=1/2`) for consistency

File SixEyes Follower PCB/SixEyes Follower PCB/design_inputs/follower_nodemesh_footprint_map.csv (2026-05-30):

RefDesPattern | Description | KiCadFootprint | Notes
U1 | ESP32-S3 DevKitC-1 dual-row socket | Connector_PinSocket_2.54mm:PinSocket_1x19_P2.54mm_Vertical x2 | Use two rows and lock orientation
U2-U5 | TMC2209 StepStick socket rows | Connector_PinSocket_2.54mm:PinSocket_1x08_P2.54mm_Vertical x2 per driver | One pair per driver module
J1_MOTOR-J4_MOTOR | Stepper connector 6-pin JST XH | Connector_JST:JST_XH_B6B-XH-A_1x06_P2.50mm_Vertical | Pins 5 and 6 are NC
J_SERVO1-J_SERVO3 | Servo connector 3-pin JST XH | Connector_JST:JST_XH_B3B-XH-A_1x03_P2.50mm_Vertical | Pin order GND +6V6 SIG
H_UART1 | Leader/follower UART header | Connector_PinHeader_2.54mm:PinHeader_1x04_P2.54mm_Vertical | Pin 4 optional +3V3
H_SD1 | MicroSD SPI board header | Connector_PinHeader_2.54mm:PinHeader_1x06_P2.54mm_Vertical | 3.3V module only
J_PWR1 | Main 24V input | TerminalBlock:TerminalBlock_bornier-2_P5.08mm | Any equivalent 2-pin 5.08mm THT is okay
TP1-TP7 | Debug test pads | TestPoint:TestPoint_Pad_D1.5mm | Optional debug points
MH1-MH4 | Mounting holes | MountingHole:MountingHole_3.2mm_M3 | Non-plated or plated per enclosure plan
R1-R17 | Through-hole resistors | Resistor_THT:R_Axial_DIN0207_L6.3mm_D2.5mm_P7.62mm_Horizontal | Includes pull-ups and optional series damping
C1 | 24V bulk capacitor | Capacitor_THT:CP_Radial_D10.0mm_P5.00mm | 470uF 35V minimum
C2-C3 | 24V local decoupling | Capacitor_THT:C_Disc_D5.0mm_W2.5mm_P5.00mm | 1uF and 100nF near TMC bank
C4 | Servo rail bulk capacitor | Capacitor_THT:CP_Radial_D10.0mm_P5.00mm | 1000uF 16V minimum
C5 | Servo rail HF bypass | Capacitor_THT:C_Disc_D5.0mm_W2.5mm_P5.00mm | 100nF near servo cluster
C6 | 3V3 bulk capacitor | Capacitor_THT:CP_Radial_D8.0mm_P3.50mm | 220uF 10V minimum
C7-C10 | TMC VIO decouplers | Capacitor_THT:C_Disc_D5.0mm_W2.5mm_P5.00mm | 100nF each at U2-U5 VIO
C11-C13 | Logic and SD local decoupling | Capacitor_THT:C_Disc_D5.0mm_W2.5mm_P5.00mm | C12 can use radial electrolytic if preferred
JP1-JPn | Wire jumpers for single-layer crossings | SixEyes_Custom:WireJumper_1x02_P2.54mm | Custom footprint in local pretty library

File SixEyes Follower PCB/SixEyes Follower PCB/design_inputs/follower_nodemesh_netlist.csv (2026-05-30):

RefDes | Block | Pin | Net | Notes
U1 | ESP32_S3_DEVBOARD_2x19 | GPIO4 | STEP_J1 | Stepper J1 step
U1 | ESP32_S3_DEVBOARD_2x19 | GPIO5 | DIR_J1 | Stepper J1 direction
U1 | ESP32_S3_DEVBOARD_2x19 | GPIO6 | EN_ALL | Shared stepper enable
U1 | ESP32_S3_DEVBOARD_2x19 | GPIO7 | PDN_J1 | TMC2209 J1 UART
U1 | ESP32_S3_DEVBOARD_2x19 | GPIO8 | STEP_J2 | Stepper J2 step
U1 | ESP32_S3_DEVBOARD_2x19 | GPIO9 | DIR_J2 | Stepper J2 direction
U1 | ESP32_S3_DEVBOARD_2x19 | GPIO11 | PDN_J2 | TMC2209 J2 UART
U1 | ESP32_S3_DEVBOARD_2x19 | GPIO12 | STEP_J3 | Stepper J3 step
U1 | ESP32_S3_DEVBOARD_2x19 | GPIO13 | DIR_J3 | Stepper J3 direction
U1 | ESP32_S3_DEVBOARD_2x19 | GPIO15 | PDN_J3 | TMC2209 J3 UART
U1 | ESP32_S3_DEVBOARD_2x19 | GPIO16 | STEP_J4 | Stepper J4 step
U1 | ESP32_S3_DEVBOARD_2x19 | GPIO17 | DIR_J4 | Stepper J4 direction
U1 | ESP32_S3_DEVBOARD_2x19 | GPIO21 | PDN_J4 | TMC2209 J4 UART
U1 | ESP32_S3_DEVBOARD_2x19 | GPIO35 | SERVO_WRIST_PITCH | Servo 1 PWM
U1 | ESP32_S3_DEVBOARD_2x19 | GPIO36 | SERVO_WRIST_YAW | Servo 2 PWM
U1 | ESP32_S3_DEVBOARD_2x19 | GPIO37 | SERVO_GRIPPER | Servo 3 PWM
U1 | ESP32_S3_DEVBOARD_2x19 | GPIO38 | UART_LEADER_RX | From leader TX
U1 | ESP32_S3_DEVBOARD_2x19 | GPIO39 | UART_LEADER_TX | To leader RX
U1 | ESP32_S3_DEVBOARD_2x19 | GPIO40 | SD_SCK | MicroSD SPI clock
U1 | ESP32_S3_DEVBOARD_2x19 | GPIO41 | SD_MISO | MicroSD SPI MISO
U1 | ESP32_S3_DEVBOARD_2x19 | GPIO42 | SD_MOSI | MicroSD SPI MOSI
U1 | ESP32_S3_DEVBOARD_2x19 | GPIO2 | SD_CS | MicroSD SPI chip select
U1 | ESP32_S3_DEVBOARD_2x19 | 3V3 | +3V3_LOGIC | Logic rail
U1 | ESP32_S3_DEVBOARD_2x19 | GND | GND | Common ground
U2 | TMC2209_DEVBOARD_2x08 | STEP | STEP_J1
U2 | TMC2209_DEVBOARD_2x08 | DIR | DIR_J1
U2 | TMC2209_DEVBOARD_2x08 | EN | EN_ALL
U2 | TMC2209_DEVBOARD_2x08 | PDN_UART | PDN_J1
U2 | TMC2209_DEVBOARD_2x08 | VIO | +3V3_LOGIC
U2 | TMC2209_DEVBOARD_2x08 | VMOT | +24V_MOTOR
U2 | TMC2209_DEVBOARD_2x08 | GND | GND
U2 | TMC2209_DEVBOARD_2x08 | OA1 | J1_MOTOR_PIN1
U2 | TMC2209_DEVBOARD_2x08 | OA2 | J1_MOTOR_PIN2
U2 | TMC2209_DEVBOARD_2x08 | OB1 | J1_MOTOR_PIN3
U2 | TMC2209_DEVBOARD_2x08 | OB2 | J1_MOTOR_PIN4
U3 | TMC2209_DEVBOARD_2x08 | STEP | STEP_J2
U3 | TMC2209_DEVBOARD_2x08 | DIR | DIR_J2
U3 | TMC2209_DEVBOARD_2x08 | EN | EN_ALL
U3 | TMC2209_DEVBOARD_2x08 | PDN_UART | PDN_J2
U3 | TMC2209_DEVBOARD_2x08 | VIO | +3V3_LOGIC
U3 | TMC2209_DEVBOARD_2x08 | VMOT | +24V_MOTOR
U3 | TMC2209_DEVBOARD_2x08 | GND | GND
U3 | TMC2209_DEVBOARD_2x08 | OA1 | J2_MOTOR_PIN1
U3 | TMC2209_DEVBOARD_2x08 | OA2 | J2_MOTOR_PIN2
U3 | TMC2209_DEVBOARD_2x08 | OB1 | J2_MOTOR_PIN3
U3 | TMC2209_DEVBOARD_2x08 | OB2 | J2_MOTOR_PIN4
U4 | TMC2209_DEVBOARD_2x08 | STEP | STEP_J3
U4 | TMC2209_DEVBOARD_2x08 | DIR | DIR_J3
U4 | TMC2209_DEVBOARD_2x08 | EN | EN_ALL
U4 | TMC2209_DEVBOARD_2x08 | PDN_UART | PDN_J3
U4 | TMC2209_DEVBOARD_2x08 | VIO | +3V3_LOGIC
U4 | TMC2209_DEVBOARD_2x08 | VMOT | +24V_MOTOR
U4 | TMC2209_DEVBOARD_2x08 | GND | GND
U4 | TMC2209_DEVBOARD_2x08 | OA1 | J3_MOTOR_PIN1
U4 | TMC2209_DEVBOARD_2x08 | OA2 | J3_MOTOR_PIN2
U4 | TMC2209_DEVBOARD_2x08 | OB1 | J3_MOTOR_PIN3
U4 | TMC2209_DEVBOARD_2x08 | OB2 | J3_MOTOR_PIN4
U5 | TMC2209_DEVBOARD_2x08 | STEP | STEP_J4
U5 | TMC2209_DEVBOARD_2x08 | DIR | DIR_J4
U5 | TMC2209_DEVBOARD_2x08 | EN | EN_ALL
U5 | TMC2209_DEVBOARD_2x08 | PDN_UART | PDN_J4
U5 | TMC2209_DEVBOARD_2x08 | VIO | +3V3_LOGIC
U5 | TMC2209_DEVBOARD_2x08 | VMOT | +24V_MOTOR
U5 | TMC2209_DEVBOARD_2x08 | GND | GND
U5 | TMC2209_DEVBOARD_2x08 | OA1 | J4_MOTOR_PIN1
U5 | TMC2209_DEVBOARD_2x08 | OA2 | J4_MOTOR_PIN2
U5 | TMC2209_DEVBOARD_2x08 | OB1 | J4_MOTOR_PIN3
U5 | TMC2209_DEVBOARD_2x08 | OB2 | J4_MOTOR_PIN4
J1_MOTOR | JST6_STEPPER_4USED | 1 | J1_MOTOR_PIN1 | COIL_A+
J1_MOTOR | JST6_STEPPER_4USED | 2 | J1_MOTOR_PIN2 | COIL_A-
J1_MOTOR | JST6_STEPPER_4USED | 3 | J1_MOTOR_PIN3 | COIL_B+
J1_MOTOR | JST6_STEPPER_4USED | 4 | J1_MOTOR_PIN4 | COIL_B-
J1_MOTOR | JST6_STEPPER_4USED | 5 | NC | No connect
J1_MOTOR | JST6_STEPPER_4USED | 6 | NC | No connect
J2_MOTOR | JST6_STEPPER_4USED | 1 | J2_MOTOR_PIN1 | COIL_A+
J2_MOTOR | JST6_STEPPER_4USED | 2 | J2_MOTOR_PIN2 | COIL_A-
J2_MOTOR | JST6_STEPPER_4USED | 3 | J2_MOTOR_PIN3 | COIL_B+
J2_MOTOR | JST6_STEPPER_4USED | 4 | J2_MOTOR_PIN4 | COIL_B-
J2_MOTOR | JST6_STEPPER_4USED | 5 | NC | No connect
J2_MOTOR | JST6_STEPPER_4USED | 6 | NC | No connect
J3_MOTOR | JST6_STEPPER_4USED | 1 | J3_MOTOR_PIN1 | COIL_A+
J3_MOTOR | JST6_STEPPER_4USED | 2 | J3_MOTOR_PIN2 | COIL_A-
J3_MOTOR | JST6_STEPPER_4USED | 3 | J3_MOTOR_PIN3 | COIL_B+
J3_MOTOR | JST6_STEPPER_4USED | 4 | J3_MOTOR_PIN4 | COIL_B-
J3_MOTOR | JST6_STEPPER_4USED | 5 | NC | No connect
J3_MOTOR | JST6_STEPPER_4USED | 6 | NC | No connect
J4_MOTOR | JST6_STEPPER_4USED | 1 | J4_MOTOR_PIN1 | COIL_A+
J4_MOTOR | JST6_STEPPER_4USED | 2 | J4_MOTOR_PIN2 | COIL_A-
J4_MOTOR | JST6_STEPPER_4USED | 3 | J4_MOTOR_PIN3 | COIL_B+
J4_MOTOR | JST6_STEPPER_4USED | 4 | J4_MOTOR_PIN4 | COIL_B-
J4_MOTOR | JST6_STEPPER_4USED | 5 | NC | No connect
J4_MOTOR | JST6_STEPPER_4USED | 6 | NC | No connect
J_SERVO1 | JST3_SERVO | 1 | GND
J_SERVO1 | JST3_SERVO | 2 | +6V6_SERVO
J_SERVO1 | JST3_SERVO | 3 | SERVO_WRIST_PITCH
J_SERVO2 | JST3_SERVO | 1 | GND
J_SERVO2 | JST3_SERVO | 2 | +6V6_SERVO
J_SERVO2 | JST3_SERVO | 3 | SERVO_WRIST_YAW
J_SERVO3 | JST3_SERVO | 1 | GND
J_SERVO3 | JST3_SERVO | 2 | +6V6_SERVO
J_SERVO3 | JST3_SERVO | 3 | SERVO_GRIPPER
H_UART1 | HDR_1x04_UART | 1 | GND
H_UART1 | HDR_1x04_UART | 2 | UART_LEADER_RX
H_UART1 | HDR_1x04_UART | 3 | UART_LEADER_TX
H_UART1 | HDR_1x04_UART | 4 | +3V3_LOGIC | Optional
H_SD1 | HDR_1x06_SD_SPI | 1 | +3V3_LOGIC
H_SD1 | HDR_1x06_SD_SPI | 2 | GND
H_SD1 | HDR_1x06_SD_SPI | 3 | SD_SCK
H_SD1 | HDR_1x06_SD_SPI | 4 | SD_MISO
H_SD1 | HDR_1x06_SD_SPI | 5 | SD_MOSI
H_SD1 | HDR_1x06_SD_SPI | 6 | SD_CS
J_PWR1 | MAIN_POWER_IN_24V | 1 | +24V_MOTOR | 24V input
J_PWR1 | MAIN_POWER_IN_24V | 2 | GND | Power return
TP1 | TESTPOINT | 1 | TP_EN_ALL | Optional debug
TP2 | TESTPOINT | 1 | TP_PDN_J1 | Optional debug
TP3 | TESTPOINT | 1 | TP_PDN_J2 | Optional debug
TP4 | TESTPOINT | 1 | TP_PDN_J3 | Optional debug
TP5 | TESTPOINT | 1 | TP_PDN_J4 | Optional debug
TP6 | TESTPOINT | 1 | TP_UART_RX | Optional debug
TP7 | TESTPOINT | 1 | TP_UART_TX | Optional debug

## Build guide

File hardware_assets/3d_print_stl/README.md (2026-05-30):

# 3D Print STL Files

Place printable STL files for SixEyes mechanical parts in this folder.

Recommended structure:
- `arm_base/`
- `joint_brackets/`
- `servo_mounts/`
- `cable_guides/`

Recommended naming format:
`<part_name>_v<major>.<minor>.stl`

Example:
`shoulder_bracket_v1.2.stl`

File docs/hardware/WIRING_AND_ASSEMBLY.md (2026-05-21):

# SixEyes Wiring & Hardware Assembly Guide

Complete reference for physically integrating the ESP32 controllers with motors, servos, and the onboard power architecture.

For dual-mode operation, hardware can be deployed in two configurations:
- **VLA Inference**: follower controller only
- **Teleoperation**: leader controller + follower controller + laptop bridge

---

## Table of Contents

1. [Parts List](#parts-list)
2. [Pinout Reference](#pinout-reference)
3. [Power Distribution](#power-distribution)
4. [Motor Wiring](#motor-wiring)
5. [Servo Wiring](#servo-wiring)
6. [Communication Wiring](#communication-wiring)
7. [Grounding Strategy](#grounding-strategy)
8. [Testing Checklist](#testing-checklist)
9. [Troubleshooting](#troubleshooting)

---

## Dual-Mode Hardware Topology

### VLA Inference Topology

```
Laptop ROS2 (USB)
  ↕
Follower ESP32-S3
  ↕
Motors + Servos
```

### Teleoperation Topology

```
Leader ESP32-C6 SuperMini (joint sensors) --USB--> Laptop Bridge --USB--> Follower ESP32-S3
                                     ↕
                                  Motors + Servos
```

**Teleoperation wiring additions**:
- Add one extra USB serial link for `leader_esp32`
- Route leader joint sensors (potentiometers/encoders) to leader ADC pins
- Keep follower motor/servo wiring unchanged

---

## Parts List

### Controller
- **Follower: ESP32-S3-WROOM-1 DevKit** (or ESP32-S3 SuperMini)
  - Dual-core 240 MHz
  - Native USB-CDC
  - 320 KB RAM, 8 MB Flash
  - GPIO: 3.3V logic

- **Leader: ESP32-C6 SuperMini**
  - Single-core RISC-V 160 MHz
  - Native USB Serial/JTAG
  - GPIO: 3.3V logic

### Stepper Motors & Drivers
- **4× NEMA23 bipolar steppers** (4-wire, 2.8A nominal)
  - Base rotation
  - Shoulder pitch (motor 1)
  - Shoulder roll (motor 2)
  - Elbow pitch (motor 3)
  - **Connectors**: 4-pin JST or terminal blocks
  
- **4× TMC2209 stepper drivers** (PDN_UART mode)
  - Integrated current sense (0.11Ω resistors installed)
  - StallGuard capability
  - **Pinout**: GND, VDD (24V), SLA (step), DIR, PDN
  - Note: PDN pin selects device on shared UART

### Servo Motors
- **3× MG996R servos** (digital, 6.6V rail, 0.17 sec/60°)
  - Wrist pitch (5-force)
  - Wrist yaw
  - Gripper control
  - **Connectors**: 3-pin header (GND, VCC, PWM)

### Power Architecture
- **24V 150W PSU input** (main rail, 6A capable)
  - Commonly found 24V industrial supplies
  - Must support 4× NEMA23 @ 1.5A each (6A total)
  - With barrel connector or terminal blocks

- **XL4016 buck converter on PCB** (servo rail)
  - Converts 24V input to 6.6V servo rail
  - Designed for high-current servo load

- **MP1584 buck converter on PCB** (logic rail)
  - Converts 24V input to 3.3V logic rail
  - Powers ESP32 logic + TMC2209 VIO domain
  
- **USB Cable** (for ESP32 power + programming)
  - Standard USB 3.0 A → micro-B or USB-C
  - Powers logic, does NOT power motors

### Wiring & Components
- **Wire gauge**:
  - 24V stepper bus: **12 AWG** (3mm²) minimum
  - 6.6V servo bus: **16 AWG** (1mm²) acceptable
  - 3.3V logic: **20 AWG** (0.5mm²)
  - Stepper UART: **22 AWG** (0.3mm²)
  
- **Connectors**:
  - JST-XH (100mils) for motors: 2-4 pin variants
  - 0.1" headers (2.54mm) for UART, GPIO
  - Power barrel connectors (5.5×2.1mm) optional
  - Terminal blocks (5mm pitch) for power distribution
  
- **Capacitors**:
  - **1000µF/35V** electrolytic (24V bulk, surge protection)
  - **1000µF/16V** electrolytic (6.6V servo rail bulk, near headers)
  - **100nF/16V** ceramic (bypass, near ESP32 VCC)
  
- **Other**:
  - Resistors: 100k/100k divider for battery voltage sensing (optional)
  - Fuses: 10A for 24V input bus, 5A for 6.6V servo rail (optional but recommended)
  - Breadboard or custom PCB for distribution point
  - Wire strippers, soldering iron, solder (60/40 Sn/Pb or lead-free)

---

## Pinout Reference

### ESP32-S3 Pin Assignments

```
┌────────────────────────────────────────────────────────┐
│  STEPPER CONTROL (TMC2209 drivers via PDN_UART)       │
├────────────────────────────────────────────────────────┤
│                                                         │
│  UART Communication (all 4 drivers on same bus):       │
│    See firmware-selected UART path in TMC driver      │
│    (PDN lines are per-driver GPIO selects below)      │
│    Speed: 115200 baud                                │
│                                                         │
│  Device Selection (PDN pins, active-low):            │
│    GPIO13 ──→ Motor 0 PDN (Base rotation)            │
│    GPIO10 ──→ Motor 1 PDN (Shoulder pitch)           │
│    GPIO16 ──→ Motor 2 PDN (Shoulder roll)            │
│    GPIO6  ──→ Motor 3 PDN (Elbow pitch)              │
│                                                         │
│  Motor Enable (all steppers):                         │
│    GPIO14 ──→ EN pin (active HIGH, drives all 4)    │
│                                                         │
└────────────────────────────────────────────────────────┘

┌────────────────────────────────────────────────────────┐
│  SERVO CONTROL (LEDC PWM, 50 Hz)                       │
├────────────────────────────────────────────────────────┤
│                                                         │
│    GPIO40 ──→ Servo 0 PWM (Pitch)                     │
│    GPIO41 ──→ Servo 1 PWM (Yaw)                       │
│    GPIO42 ──→ Servo 2 PWM (Gripper)                   │
│                                                         │
│  PWM Spec:                                             │
│    Frequency: 50 Hz                                    │
│    Pulse range: 500-2500 µs                           │
│    Resolution: 16-bit LEDC                           │
│                                                         │
└────────────────────────────────────────────────────────┘

┌────────────────────────────────────────────────────────┐
│  COMMUNICATION & DIAGNOSTICS                           │
├────────────────────────────────────────────────────────┤
│                                                         │
│  USB-CDC (native ESP32-S3):                           │
│    Micro-USB port ──→ Serial I/O                      │
│    Baud: 115200 (virtual)                             │
│    Format: ASCII heartbeat protocol                   │
│      RX: "HB:0,<seq>\n"                               │
│      TX: "SB:<fault>,<en>,<ros2>\n"                  │
│                                                         │
│  Optional LED:                                        │
│    GPIO46 ──→ Status LED (diagnostics)               │
│                                                         │
│  Optional ADC:                                        │
│    GPIO3  ──→ Battery voltage (divide by 2)          │
│    GPIO4  ──→ Current sense (TMC diagnostics)        │
│                                                         │
└────────────────────────────────────────────────────────┘

┌────────────────────────────────────────────────────────┐
│  POWER DISTRIBUTION                                    │
├────────────────────────────────────────────────────────┤
│                                                         │
│  VCC / GND (3.3V logic):                              │
│    GPIO: 3.3V (all GPIO operate at 3.3V)             │
│    USB or LDO regulated                               │
│                                                         │
│  Reserved / Strapping:                                │
│    GPIO1, GPIO2: Boot strapping pins                 │
│    GPIO8, GPIO9: Flash SPI (reserved)                │
│    GPIO42, GPIO43: UART console (optional)           │
│                                                         │
└────────────────────────────────────────────────────────┘
```

### TMC2209 Driver Pin Description

```
┌──────────────────────────────────────────────────────┐
│           TMC2209 Pin Mapping (PDN_UART Mode)       │
├──────────────────────────────────────────────────────┤
│                                                      │
│  Pin 1 (GND):      Ground                           │
│  Pin 2 (VDD):      24V stepper supply               │
│  Pin 3 (SLA):      UART Si (shared bus)             │
│  Pin 4 (SOA):      UART So (shared bus)             │
│  Pin 5 (PDN):      Device select (GPIO to ESP32)   │
│                    Active low: pull to GND          │
│                    Idle high: leave floating        │
│  Pin 6 (GND):      Ground return                    │
│                                                      │
│  Configuration (hardware, not firmware):            │
│    ├─ Test pin grounded (always)                    │
│    ├─ Sense resistor: 0.11Ω between GND and motor  │
│    ├─ Flying cap across VDD-GND (100µF typical)    │
│    └─ UART protection: no extra filtering needed    │
│                                                      │
│  Operation:                                         │
│    • Default: PDN floating (device active)          │
│    • To disable device: Pull PDN to GND             │
│    • UART accessible on all 4 drivers             │
│    • CRC-8 calculation done automatically          │
│                                                      │
└──────────────────────────────────────────────────────┘
```

---

## Power Distribution

### Main Power Bus Architecture

```
┌─────────────────────────────────────────────────────────────────┐
│                   POWER SUPPLY CONNECTIONS                      │
└─────────────────────────────────────────────────────────────────┘

24V STEPPER BUS (6A max)
═════════════════════════

    24V PSU
    +24V ────┬─── Filter Capacitor (1000µF/35V) ───┬─→ Power Bus
             │                                       │
             ├─ Thick wire (12 AWG) ─── ─ ─ ─ ──→ Distribution Point
             │
             └─ Return GND ── ═══════════════════════ ─ ─ ─ ─ → GND Bus

From Distribution Point → TMC2209 Driver Inputs:
  • VDD pin: 24V (tight tolerance, ±10%)
  • GND pin: Ground return (common star point)

STEPPER MOTORS:
  4× NEMA23 @ 1.5A each = 6A max bus current
  Connected via stepper drivers (not direct to bus)

6.6V SERVO BUS (XL4016, ~3A design target)
═══════════════════════════════════════════

    24V Input Bus
      │
      └─→ XL4016 Buck (on PCB) ──→ 6.6V Servo Bus
                                   │
                                   ├─ Filter Capacitor (≥1000µF/16V)
                                   ├─ Wire (16 AWG acceptable) → Servo Headers
                                   └─ Return GND → Common Star Ground

From Servo Bus → Servo Connectors:
  • VCC pin: 6.6V (target ±0.3V)
  • GND pin: Ground return (common star point)

SERVOS:
  3× MG996R class @ up to ~1A each (load-dependent)

3.3V LOGIC SUPPLY (MP1584 on PCB)
══════════════════════════════════

    24V Input Bus
      │
      └─→ MP1584 Buck (on PCB) ──→ 3.3V Logic Rail

Filter:
  • ≥22µF input + ≥22µF output at converter
  • 100nF bypass caps near MCU/logic loads

LOGIC SIGNALS:
  All GPIO: 3.3V
  TMC2209 UART: 3.3V (TTL compatible)
  Servo PWM: 3.3V (servos tolerate this)

EXTERNAL CONNECTION BLOCK (Ground Star Point)
════════════════════════════════════════════════

        24V PSU GND ──┐
                      ├─→ STAR POINT (chassis/PCB ground)
        6.6V rail GND ─┤
                      │
        USB GND ──────┤
                      │
        (No loops! Single point of reference)
                      │
                    From here:
                      ├─ Thick wire to ESP32 GND
                      ├─ Thick wire to TMC2209 GND inputs
                      ├─ Thick wire to servo power GND
                      └─ Return wire from motors/servos
```

### Recommended Power Supply Specifications

| Supply | Voltage | Current | Wire Gauge | Connector | Notes |
|:---|:---:|:---:|:---:|:---:|:---|
| Main Input | 24V | 6A | 12 AWG (3mm²) | 5.5×2.1mm barrel | Feeds TMC2209 VM + onboard bucks |
| Servo Rail | 6.6V | 3A | 16 AWG (1mm²) | Terminal block | From onboard XL4016 buck |
| Logic Rail | 3.3V | 500mA+ | 20 AWG (0.5mm²) | PCB internal rail | From onboard MP1584 buck |

---

## Motor Wiring

### NEMA23 Stepper Motor Connection

```
┌────────────────────────────────────────────────────┐
│         NEMA23 STEPPER (4-wire Bipolar)           │
├────────────────────────────────────────────────────┤
│                                                    │
│  Connector (typical JST-XH 4-pin):                │
│    Pin 1: Motor A+ (red)                          │
│    Pin 2: Motor A- (blue)                         │
│    Pin 3: Motor B+ (yellow)                       │
│    Pin 4: Motor B- (green)                        │
│                                                    │
│  CRITICAL: DO NOT SWAP A/B PAIRS!                 │
│    (will cause motor to jitter instead of run)    │
│                                                    │
│  Connection to TMC2209:                           │
│    Motor A±  ──→ COIL A on driver                 │
│    Motor B±  ──→ COIL B on driver                 │
│                                                    │
│  Current Setting:                                 │
│    Standard NEMA23: 2.8A nominal                 │
│    Set VREF on TMC2209 for 1.5A running          │
│    Formula: AMPS = VREF × 2.0 (check datasheet) │
│    For 1.5A: Set VREF ≈ 0.75V potentiometer     │
│                                                    │
└────────────────────────────────────────────────────┘

ASSEMBLY FOR 4 MOTORS:
════════════════════════

Motor 0 (Base):
  JST-XH 4-pin ──→ TMC2209 Driver #0 COIL inputs
  TMC2209 PDN ──→ GPIO13 (pull to GND to disable)

Motor 1 (Shoulder Pitch):
  JST-XH 4-pin ──→ TMC2209 Driver #1 COIL inputs
  TMC2209 PDN ──→ GPIO10 (pull to GND to disable)

Motor 2 (Shoulder Roll):
  JST-XH 4-pin ──→ TMC2209 Driver #2 COIL inputs
  TMC2209 PDN ──→ GPIO16 (pull to GND to disable)

Motor 3 (Elbow):
  JST-XH 4-pin ──→ TMC2209 Driver #3 COIL inputs
  TMC2209 PDN ──→ GPIO6 (pull to GND to disable)

SHARED UART BUS (all 4 drivers):
  Use firmware-selected UART pins for TMC2209 bus IO.
  Inter-board UART is reserved on GPIO18 (RX) and GPIO17 (TX).
  
  Note: Si/So are UART daisy-chained internally.
        All drivers listen on same bus.
        PDN pin selection determines which responds.

MOTOR ENABLE:
  GPIO14 (EN) ──→ EN input on all 4 TMC2209 boards
               (pull HIGH to enable, LOW to disable)
```

### Proper Motor Polarity Testing

```
BEFORE POWERED-UP TESTING:
═════════════════════════════

1. Disconnect 24V power supply
2. Connect motor A+ and A- directly to battery (2-3V)
3. Motor shaft should rotate smoothly (no cogging)
4. If jittery: swap A± wires and test again
5. When smooth: mark correct polarity (red=+, black=-)
6. Repeat for B coil pair
7. Once confirmed, solder JST connectors

TIP: Use multimeter continuity to trace wires back to
     motor windings if color coding is unclear.

AFTER ASSEMBLY:
════════════════

If motor doesn't step:
  1. Check VREF pot setting (should be 0.75V for 1.5A)
  2. Verify UART communication (scope Si/So lines)
  3. Swap A± wires (coil polarity wrong)
  4. Swap B± wires (coil polarity wrong)
  5. Check PDN signal from ESP32 (should be HIGH/floating)
```

---

## Servo Wiring

### MG996R Servo Connection

```
┌────────────────────────────────────────────────────┐
│         MG996R SERVO (Digital, 50 Hz PWM)         │
├────────────────────────────────────────────────────┤
│                                                    │
│  Connector (3-pin header, 2.54mm spacing):        │
│    Pin 1: GND (brown, black)                      │
│    Pin 2: VCC (red)                               │
│    Pin 3: PWM (orange, yellow)                    │
│                                                    │
│  Signal Mapping:                                  │
│    500 µs  → -90° (far left)                      │
│    1500 µs → 0° (center, neutral)                 │
│    2500 µs → +90° (far right)                     │
│                                                    │
│  For 0-180° range (SixEyes):                      │
│    500 µs  → 0°                                   │
│    1500 µs → 90° (center, SAFE POWER-UP)         │
│    2500 µs → 180°                                │
│                                                    │
│  PWM Frequency: 50 Hz (20 ms period)             │
│    ├─ Pulse width: 0.5-2.5 ms (varies)           │
│    └─ Low period: fills rest of 20 ms            │
│                                                    │
│  Current Draw:                                    │
│    Idle: ~10 mA                                   │
│    Under load: ~1000 mA (1A peak)                │
│    Total for 3 servos: ~3A max                   │
│                                                    │
└────────────────────────────────────────────────────┘

ASSEMBLY FOR 3 SERVOS:
═══════════════════════

Servo 0 (Pitch):
  GND ─→ 6.6V Power Bus GND
  VCC ─→ 6.6V Power Bus +6.6V
  PWM ─→ GPIO40 (LEDC channel 0)

Servo 1 (Yaw):
  GND ─→ 6.6V Power Bus GND
  VCC ─→ 6.6V Power Bus +6.6V
  PWM ─→ GPIO41 (LEDC channel 1)

Servo 2 (Gripper):
  GND ─→ 6.6V Power Bus GND
  VCC ─→ 6.6V Power Bus +6.6V
  PWM ─→ GPIO42 (LEDC channel 2)

POWER-UP SEQUENCE:
═════════════════

1. All servos should initialize to 90° (neutral)
2. Verify mechanically: all servo arms point straight
3. If not: adjust trim on servo potentiometer (inside)
   (Or adjust in code if SixEyes uses offset calibration)

CONNECTING SERVOS UNDER LOAD:
═════════════════════════════

SAFETY CRITICAL:
  1. Always start at 90° (neutral) position
  2. Ramp PWM smoothly to target angle (no jerks)
  3. Monitor current draw (should stay <1A per servo)
  4. Do NOT enable servos while gripper has load
     (high stall current, ~2A)
  5. Use mechanical limit stops, not software only
```

### Servo Power Management

```
VOLTAGE SAFETY:
════════════════

Servo rail target for this PCB revision: 6.6V (from XL4016)
  ├─ Verify servo rail before plugging servos
  ├─ Use neutral startup pose and current-limited bring-up
  └─ Keep bulk capacitance near servo headers (≥1000µF)

CURRENT SPIKE PROTECTION:
═════════════════════════

Each servo can draw 1A briefly when stalled.
3 servos = 3A peak possible.

Recommended power budget:
  ├─ Normal operation: ~100 mA idle + load
  ├─ Smooth motion: ~300 mA continuous
  ├─ Peak spike: ~3 A (brief, <1 sec)
  └─ 6.6V rail path must handle 3A continuous at minimum

If using a temporary external servo source for bench checks:
  ├─ Regulated bench supply set to 6.6V (current-limited)
  ├─ Verify polarity and rail stability before connecting servos
  └─ Keep the same common-ground star-point strategy

RECOMMENDED: onboard XL4016 6.6V rail fed from stable 24V input
```

---

## Communication Wiring

### USB-CDC Connection

```
┌──────────────────────────────────────────────────────┐
│         USB-CDC COMMUNICATION (Native ESP32-S3)     │
├──────────────────────────────────────────────────────┤
│                                                      │
│  Physical Connector:                                │
│    Micro-USB-B or USB-C (depending on board)       │
│    Type: Standard USB 3.0 compatible               │
│                                                      │
│  Connection to Laptop:                             │
│    USB-A ←→ USB-B/C cable (quality matters!)       │
│    Typical distance: 1-3 meters (shielded cable)   │
│                                                      │
│  Electrical Spec:                                  │
│    Power: 5V @ 500mA (USB device)                  │
│    Data: Full-speed USB (12 Mbps)                 │
│    Protocol: CDC/ACM virtual COM port             │
│                                                      │
│  Virtual COM Port (Windows/Linux/Mac):             │
│    Windows: COM3, COM4, etc. (auto-assign)         │
│    Linux: /dev/ttyACM0, /dev/ttyUSB0              │
│    Mac: /dev/tty.usbmodem*, /dev/tty.usbserial*  │
│                                                      │
│  Baud Rate (virtual, doesn't matter):             │
│    115200 baud (standard for compatibility)       │
│    Hardware is full USB speed regardless          │
│                                                      │
└──────────────────────────────────────────────────────┘

HEARTBEAT PROTOCOL:
═════════════════════

Direction: ROS2 (laptop) → Firmware (ESP32)
Format: "HB:0,<sequence>\n"
Example: "HB:0,42\n"
Speed: 50 Hz recommended

Direction: Firmware → ROS2 (laptop)
Format: "SB:<fault>,<motors_en>,<ros2>\n"
Example: "SB:0,1,1\n"
Speed: 10 Hz

TESTING CONNECTION:
═══════════════════

Linux:
  $ picocom /dev/ttyACM0 -b 115200
  (or minicom, screen, etc.)

Windows (PowerShell):
  > [System.IO.Ports.SerialPort]::GetPortNames()
  > py -c "import serial; s=serial.Serial('COM3',115200); print(s.readline())"

macOS:
  $ ls /dev/tty.usb*
  $ screen /dev/tty.usbmodem* 115200
```

### Optional UART for Expansion

```
┌──────────────────────────────────────────────────────┐
│    OPTIONAL: Serial2 (GPIO17/18) for Future Use    │
├──────────────────────────────────────────────────────┤
│                                                      │
│  Currently Used For:                                │
│    TMC2209 UART (Si/So daisy-chain)                │
│    All 4 stepper drivers on same bus               │
│                                                      │
│  Future Expansion:                                 │
│    Not available (fully allocated to TMC2209)      │
│    Would need GPIO17/18 for other purposes         │
│                                                      │
│  Available GPIO for Custom Expansion:              │
│    GPIO1, GPIO2: Strapping pins (use with care)   │
│    GPIO8, GPIO9: Usually SPI Flash (reserved)      │
│    GPIO42, GPIO43: UART monitor console (free)    │
│                                                      │
│  If Serial2 is needed for something else:          │
│    ├─ Move TMC2209 to SPI mode (need SPI pins)    │
│    └─ Requires hardware changes & firmware update  │
│                                                      │
└──────────────────────────────────────────────────────┘
```

---

## Grounding Strategy

### Star Grounding (Critical for Safety)

```
PROBLEM: Ground Loops
═════════════════════

Multiple disconnected GND connections can cause:
  ├─ Voltage offsets (3.3V logic sees different reference than 24V stepper GND)
  ├─ Noise coupling (high-current stepper ripple affects logic)
  ├─ False fault conditions (noise triggers stall detection)
  └─ Unpredictable electromagnetic behavior

SOLUTION: STAR GROUNDING
═════════════════════════

Single reference point (STAR):
  
        24V PSU GND ──┐
                      ├──→ STAR POINT (central node)
        6.6V rail GND ─┤
                      │
        USB GND ──────┘

From STAR POINT (busbar or PCB pad):

  • Thick wire (12 AWG) to ESP32 GND pin
  • Thick wire (12 AWG) to all TMC2209 GND inputs
  • Thick wire (10 AWG) to servo power distribution GND
  • Thick wire (10 AWG) back to all PSU GND returns

KEY PROPERTIES:
  ├─ All GND connections originate from ONE point
  ├─ No loops (no multiple paths for current)
  ├─ High current (24V stepper) has dedicated thick wire
  ├─ All logic signals reference same GND
  └─ Noise stays isolated to each rail

IMPLEMENTATION:
════════════════

Option 1: Busbar (recommended)
  • Copper busbar with multiple screw terminals
  • All grounds screw into same busbar
  • Bolted to chassis (might add capacitance,  low impedance)

Option 2: PCB pad (if building custom)
  • Dedicated large polygon fill on PCB
  • All grounds connect to edge of polygon
  • Via stitching prevents loop currents

Option 3: Breadboard (temporary testing only)
  • All GND lines to red rail (same row)
  • Then one thick wire from rail to PSU GND
  • NOT suitable for actual robot (too much noise)

WIRE SELECTION:
════════════════

24V stepper GND: 12 AWG (3.3mm²) or thicker
6.6V servo GND:  12 AWG (3.3mm²) or thicker
3.3V logic GND:  16 AWG (1.3mm²) acceptable
UART signal:     22 AWG (0.3mm²) standard

(Smaller gauge = higher resistance = larger voltage drop)
```

### Shielding (Optional but Recommended)

```
HIGH-CURRENT POWER LINES:
═════════════════════════

24V stepper bus can cause EMI:
  ├─ Inductor (stepper coil) switching at high frequency
  ├─ Sharp current transients (PWM)
  └─ Can couple into logic signals nearby

MITIGATION:
  ├─ Route 24V wires away from logic signals
  ├─ Use shielded cable for UART (Si/So) if long runs
  ├─ Keep ESP32 board away from stepper drivers
  ├─ Add ferrite cores on UART wires (optional)
  └─ Proper grounding is most important

FERRITE CORE USAGE:
═════════════════════

If using, choose:
  ├─ Type: FT240-43 or similar (MHz range)
  ├─ Location: Near TMC2209 driver outputs
  ├─ Winding: Wrap UART wires 2-3 times
  └─ Benefit: Attenuates high-frequency noise

But: Proper PSU with bulk caps usually sufficient.
```

---

## Testing Checklist

### Pre-Power Checks

- [ ] No visible solder bridges between pins
- [ ] All JST connectors fully seated and latched
- [ ] Motor A/B coils confirmed correct polarity (continuity test)
- [ ] Servo range verified (500-2500 µs with multimeter)
- [ ] CPU and driver boards don't touch (no shorts)
- [ ] No loose wires dangling near power rails
- [ ] All capacitors oriented correctly (stripe = negative)
- [ ] Fuses rating correct (10A for 24V input, 5A for 6.6V rail)

### Power-On Sequence

1. **USB Only (no stepper/servo power)**:
   - [ ] ESP32 board powers up (LED blinks if present)
   - [ ] Check Device Manager / `/dev/ttyACM0`
   - [ ] Serial monitor shows startup messages
   - [ ] No shorts detected (board doesn't brown out)

2. **Add 24V Stepper Power**:
   - [ ] LED doesn't change (isolated supplies)
   - [ ] No audible buzz from stepper drivers
   - [ ] Measure: 24V ± 0.5V at TMC2209 VDD pins
   - [ ] Measure: 0V at all GND (no offset)

3. **Verify 6.6V Servo Rail (XL4016)**:
   - [ ] Servos should initialize to 90° (neutral)
   - [ ] No servo jerks or movement
  - [ ] Measure: 6.6V ± 0.3V at servo VCC pins
   - [ ] Current draw: ~100 mA idle (3 servos)

### Communication Verification

- [ ] Send manual heartbeat: `echo "HB:0,0" > /dev/ttyACM0`
- [ ] Monitor serial output: `picocom /dev/ttyACM0 -b 115200`
- [ ] Observe "EN pin LOW" message (waiting for heartbeat)
- [ ] Send another heartbeat: observe "EN pin HIGH"
- [ ] Wait 500 ms without sending: observe "HEARTBEAT_TIMEOUT"
- [ ] Send heartbeats continuously: see `SB:0,1,1` (status packets)

### Motor Verification (No Load)

- [ ] Stepper motors: slight resistance to manual rotation (detent torque)
- [ ] No audible clicking or grinding
- [ ] Servo arms move smoothly from 0° to 180°
- [ ] Servo current stays under 1A per servo

### Final Integration

- [ ] Firmware compiles without warnings
- [ ] Memory usage < 50% (verify via `pio run` output)
- [ ] All modules initialized in startup log
- [ ] Control loop runs at stable 400 Hz
- [ ] No spurious fault conditions from noise

---

## Troubleshooting

### Symptom: ESP32 Board Won't Power Up

**Checks**:
1. USB cable: Try different cable (some cheap cables power only)
2. USB port: Try different PC port
3. Micro-USB connector: May be loose, jiggle gently
4. Solder joints: Check for whiskers or bridges near USB pins
5. LDO regulator: Feel if it's getting hot (indicates short)

**Fix**:
- Replace USB cable first (most common)
- Clean USB connector with alcohol & lint-free cloth
- If still fails: board may be DOA (return/replace)

---

### Symptom: No Serial Port Visible in Device Manager (Windows)

**Checks**:
1. Install CH340 driver (common for cheap ESP32 boards)
2. Check Device Manager for "Unknown Device" or "Other devices"
3. Verify USB cable is data-capable (not power-only)

**Fix**:
```powershell
# Download driver from: https://github.com/WCHSoftware/ch341ser_windows
# Install and reboot
# Then check:
[System.IO.Ports.SerialPort]::GetPortNames()
```

---

### Symptom: Stepper Motors Don't Step

**Sequence of Checks**:
1. **Verify UART connection**:
   - Scope GPIO17/18 at UART pins
   - Should see TTL data at 115200 baud
   - If silent: check wire connections

2. **Check VREF potentiometer**:
   - Measure with multimeter between pot GND and wiper
   - Should be ~0.75V (for 1.5A setting)
   - Adjust if needed (tiny potentiometer, use fine tool)

3. **Verify motor coil polarity**:
   - Do OFF test: disconnect driver, connect 3V directly
   - Motor should rotate smoothly (no cogging)
   - If jittery: swap A± or B± wires

4. **Check PDN signals**:
  - GPIO13/10/16/6 should be HIGH when idle (3.3V)
   - Should pulse LOW during UART communication
   - If stuck LOW: GPIO might be shorted to GND

5. **Confirm firmware mode**:
   - Serial monitor should show control loop running
   - Should show "EN pin" status messages
   - If stuck initializing: check FreeRTOS task creation

**Last resort**: Use TMCStepper library diagnostic mode to read DRV_STATUS register

---

### Symptom: Servos Twitch or Move Unexpectedly

**Root Causes**:
1. **Power supply sagging**:
  - Measure 6.6V rail under load
  - Should stay approximately 6.3V-6.9V
  - If it drops significantly below target: check 24V source, XL4016 settings, and wiring

2. **Noise coupling from stepper PWM**:
   - PWM switching noise affects servo signal
   - Solution: **Shielded cable** for servo PWM lines
   - Or: **Ferrite cores** on servo connectors

3. **Unstable ESP32 supply**:
   - If 3.3V rail has noise, all GPIO become noisy
   - Check: 100nF bypass cap directly at ESP32 VCC
   - Add larger 10µF cap if still noisy

4. **Software issue** (PID tuning, interrupt conflicts):
   - Unlikely if other motors work fine
   - Check if only one servo affected (pinpoint issue)

**Fix**:
1. Check voltage sag with multimeter under load  
2. Add shielded cable to servo PWM lines
3. Verify 100nF bypass cap is present & tight

---

### Symptom: Intermittent Communication Losses

**Symptoms**: Heartbeat timeout even when sending heartbeats consistently

**Root Causes**:
1. **USB cable quality**:
   - Bad USB cable = dropped packets
   - Try different cable (new, thick, well-insulated)

2. **EMI from stepper PWM**:
   - High current switching couples into UART/USB
   - Solution: Better shielding or separate power grounds

3. **Timing glitch** (rare):
   - Control loop jitter might cause misalignment
   - Measure actual loop period with scope on GPIO
   - Should be exactly 2.5 ms ± 10 µs

**Fix Priority**:
1. Replace USB cable (cheapest, most likely)
2. Verify USB shielded, proper routing away from 24V
3. Add ferrite cores to UART / USB lines
4. Check ESP32 power supply quality (noise on scope)

---

### Symptom: Motor Enable Pin (GPIO6) Stuck LOW

**Checks**:
1. Measure GPIO6 voltage:
   - Should be HIGH (3.3V) at startup
   - If stuck LOW: GPIO shorted to GND

2. Check PCB/breadboard for bridges:
   - Visual inspection near GPIO6
   - Use multimeter continuity test from GPIO6 to GND
   - Check underside of wires (might be soldered by accident)

3. Verify firmware initialization:
   - Serial monitor should show "EN pin HIGH" message
   - If message missing: SafetyTask didn't init properly

**Fix**:
- Remove any solder bridges / shorts
- Reflow GPIO6 connection if using soldered header
- If still stuck: GPIO pin might be damaged (replace board)

---

### Symptom: 24V PSU Buzzing Under Load

**Cause**: Insufficient capacitance or weak PSU

**Fixes**:
1. Add larger bulk capacitor (2200µF/35V instead of 1000µF)
2. Verify PSU can supply 6A continuous
3. Check wire gauge (12 AWG minimum for 24V bus)
4. Ensure good solder joints on capacitor leads

**Result**: Should be quiet or very soft hum (normal)

---

## Quick Reference Card

### Power Wiring Jumper

```
24V PSU (+):       12 AWG (THICK) ──→ Main input bus (TMC2209 VM + onboard bucks)
6.6V rail (+):     16 AWG (MEDIUM) ──→ Servo VCC & capacitor  
3.3V rail:         PCB-distributed ──→ ESP32/TMC2209 logic domain

STAR GROUND:       12 AWG (THICK) ────┬─→ ESP32 GND
(all come here)                        ├─→ All TMC2209 GND
                                       ├─→ Servo power GND
                                       └─→ All PSU GND returns
```

### GPIO Quick Map

```
GPIO13  = Motor 0 PDN (active LOW)
GPIO10  = Motor 1 PDN (active LOW)
GPIO16  = Motor 2 PDN (active LOW)
GPIO6   = Motor 3 PDN (active LOW)
GPIO14  = Motor EN (active HIGH)
GPIO18  = UART_LEADER_RX
GPIO17  = UART_LEADER_TX
GPIO35  = SD_MOSI
GPIO36  = SD_SCK
GPIO37  = SD_MISO
GPIO38  = SD_CS
GPIO39  = SD_CD
GPIO40  = Servo 0 PWM
GPIO41  = Servo 1 PWM
GPIO42  = Servo 2 PWM
```

### Power Consumption Budget

```
Idle (no motors):             low current on 24V input (logic + idle rails)
Smooth motion (1 stepper):    ~1.5 A @ 24V + servo rail dynamic current
Peak (all steppers + servos): ~6 A @ 24V + ~3 A on 6.6V servo rail path
```

---

**Wiring complete! Proceed to Flashing Docs for deployment. ✅**

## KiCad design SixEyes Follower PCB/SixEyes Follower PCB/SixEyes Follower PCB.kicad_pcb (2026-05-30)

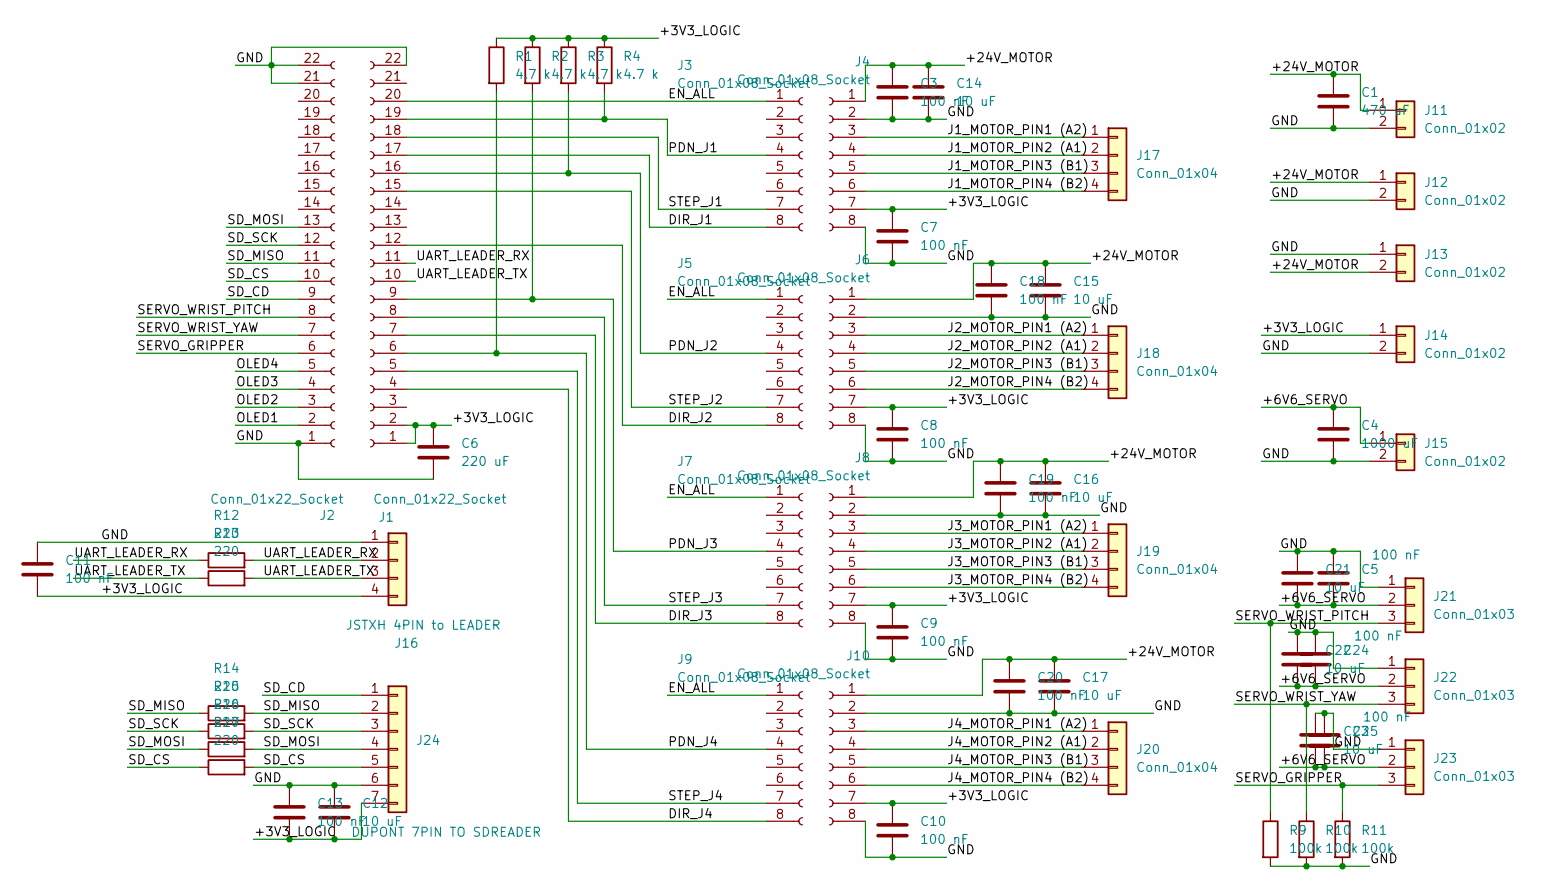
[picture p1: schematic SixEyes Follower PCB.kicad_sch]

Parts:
C1: 470 uF; CP_Radial_D10.0mm_P5.00mm
C3, C5, C7, C8, C9, C10, C11, C13, C18, C19, C20, C24, C25: 100 nF; C_Disc_D5.0mm_W2.5mm_P5.00mm
C4: 1000 uF; CP_Radial_D10.0mm_P5.00mm
C6: 220 uF; C_Disc_D5.0mm_W2.5mm_P5.00mm
C12, C14, C15, C16, C17, C21, C22, C23: 10 uF; CP_Radial_D8.0mm_P3.50mm
J1, J2: Conn_01x22_Socket; PinSocket_1x22_P2.54mm_Vertical
J3, J4, J5, J6, J7, J8, J9, J10: Conn_01x08_Socket; PinSocket_1x08_P2.54mm_Vertical
J11, J12, J13, J14, J15: Conn_01x02; TerminalBlock_Phoenix_MKDS-1,5-2_1x02_P5.00mm_Horizontal
J16: JSTXH 4PIN to LEADER; JST_XH_B4B-XH-A_1x04_P2.50mm_Vertical
J17, J18, J19, J20: Conn_01x04; JST_XH_B4B-XH-A_1x04_P2.50mm_Vertical
J21, J22, J23: Conn_01x03; JST_XH_B3B-XH-A_1x03_P2.50mm_Vertical
J24: DUPONT 7PIN TO SDREADER; PinSocket_1x07_P2.54mm_Vertical
R1, R2, R3, R4: 4.7 k; R_Axial_DIN0207_L6.3mm_D2.5mm_P7.62mm_Horizontal
R9, R10, R11: 100k; R_Axial_DIN0207_L6.3mm_D2.5mm_P7.62mm_Horizontal
R12, R13, R14, R15, R16, R17: 220; R_Axial_DIN0207_L6.3mm_D2.5mm_P7.62mm_Horizontal

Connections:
/+3V3_LOGIC: C6.1, C7.1, C8.1, C9.1, C10.1, C11.2, C12.2, C13.2, J1.1 (3V3), J1.2, J4.7, J6.7, J8.7, J10.7, J14.1, J16.4, J24.7, R1.1, R2.1, R3.1, R4.1
/+6V6_SERVO: C4.1, C5.2, C21.2, C22.2, C23.2, C24.2, C25.2, J15.1, J21.2, J22.2, J23.2
/+24V_MOTOR: C1.1, C3.1, C14.1, C15.1, C16.1, C17.1, C18.1, C19.1, C20.1, J4.1, J6.1, J8.1, J10.1, J11.1, J12.1, J13.2
/DIR_J1: J1.17, J3.8
/DIR_J2: J1.12, J5.8
/DIR_J3: J1.7, J7.8
/DIR_J4: J1.4, J9.8
/EN_ALL: J1.20, J3.1, J5.1, J7.1, J9.1
/GND: C1.2, C3.2, C4.2, C5.1, C6.2, C7.2, C8.2, C9.2, C10.2, C11.1, C12.1, C13.1, C14.2, C15.2, C16.2, C17.2, C18.2, C19.2, C20.2, C21.1, C22.1, C23.1, C24.1, C25.1, J1.22, J2.1, J2.21, J2.22, J4.2, J4.8, J6.2, J6.8, J8.2, J8.8, J10.2, J10.8, J11.2, J12.2, J13.1, J14.2, J15.2, J16.1, J21.1, J22.1, J23.1, J24.6, R9.2, R10.2, R11.2
/J1_MOTOR_PIN1 (A2): J4.3, J17.1
/J1_MOTOR_PIN2 (A1): J4.4, J17.2
/J1_MOTOR_PIN3 (B1): J4.5, J17.3
/J1_MOTOR_PIN4 (B2): J4.6, J17.4
/J2_MOTOR_PIN1 (A2): J6.3, J18.1
/J2_MOTOR_PIN2 (A1): J6.4, J18.2
/J2_MOTOR_PIN3 (B1): J6.5, J18.3
/J2_MOTOR_PIN4 (B2): J6.6, J18.4
/J3_MOTOR_PIN1 (A2): J8.3, J19.1
/J3_MOTOR_PIN2 (A1): J8.4, J19.2
/J3_MOTOR_PIN3 (B1): J8.5, J19.3
/J3_MOTOR_PIN4 (B2): J8.6, J19.4
/J4_MOTOR_PIN1 (A2): J10.3, J20.1
/J4_MOTOR_PIN2 (A1): J10.4, J20.2
/J4_MOTOR_PIN3 (B1): J10.5, J20.3
/J4_MOTOR_PIN4 (B2): J10.6, J20.4
/OLED1: J2.2
/OLED2: J2.3
/OLED3: J2.4
/OLED4: J2.5
/PDN_J1: J1.19, J3.4, R4.2
/PDN_J2: J1.16, J5.4, R3.2
/PDN_J3: J1.9, J7.4, R2.2
/PDN_J4: J1.6, J9.4, R1.2
/SD_CD: J2.9, J24.1
/SD_CS: J2.10, J24.5, R17.1, R17.2
/SD_MISO: J2.11, J24.2, R14.1, R14.2
/SD_MOSI: J2.13, J24.4, R16.1, R16.2
/SD_SCK: J2.12, J24.3, R15.1, R15.2
/SERVO_GRIPPER: J2.6, J23.3, R11.1
/SERVO_WRIST_PITCH: J2.8, J21.3, R9.1
/SERVO_WRIST_YAW: J2.7, J22.3, R10.1
/STEP_J1: J1.18, J3.7
/STEP_J2: J1.15, J5.7
/STEP_J3: J1.8, J7.7
/STEP_J4: J1.5, J9.7
/UART_LEADER_RX: J1.11, J16.2, R12.1, R12.2
/UART_LEADER_TX: J1.10, J16.3, R13.1, R13.2

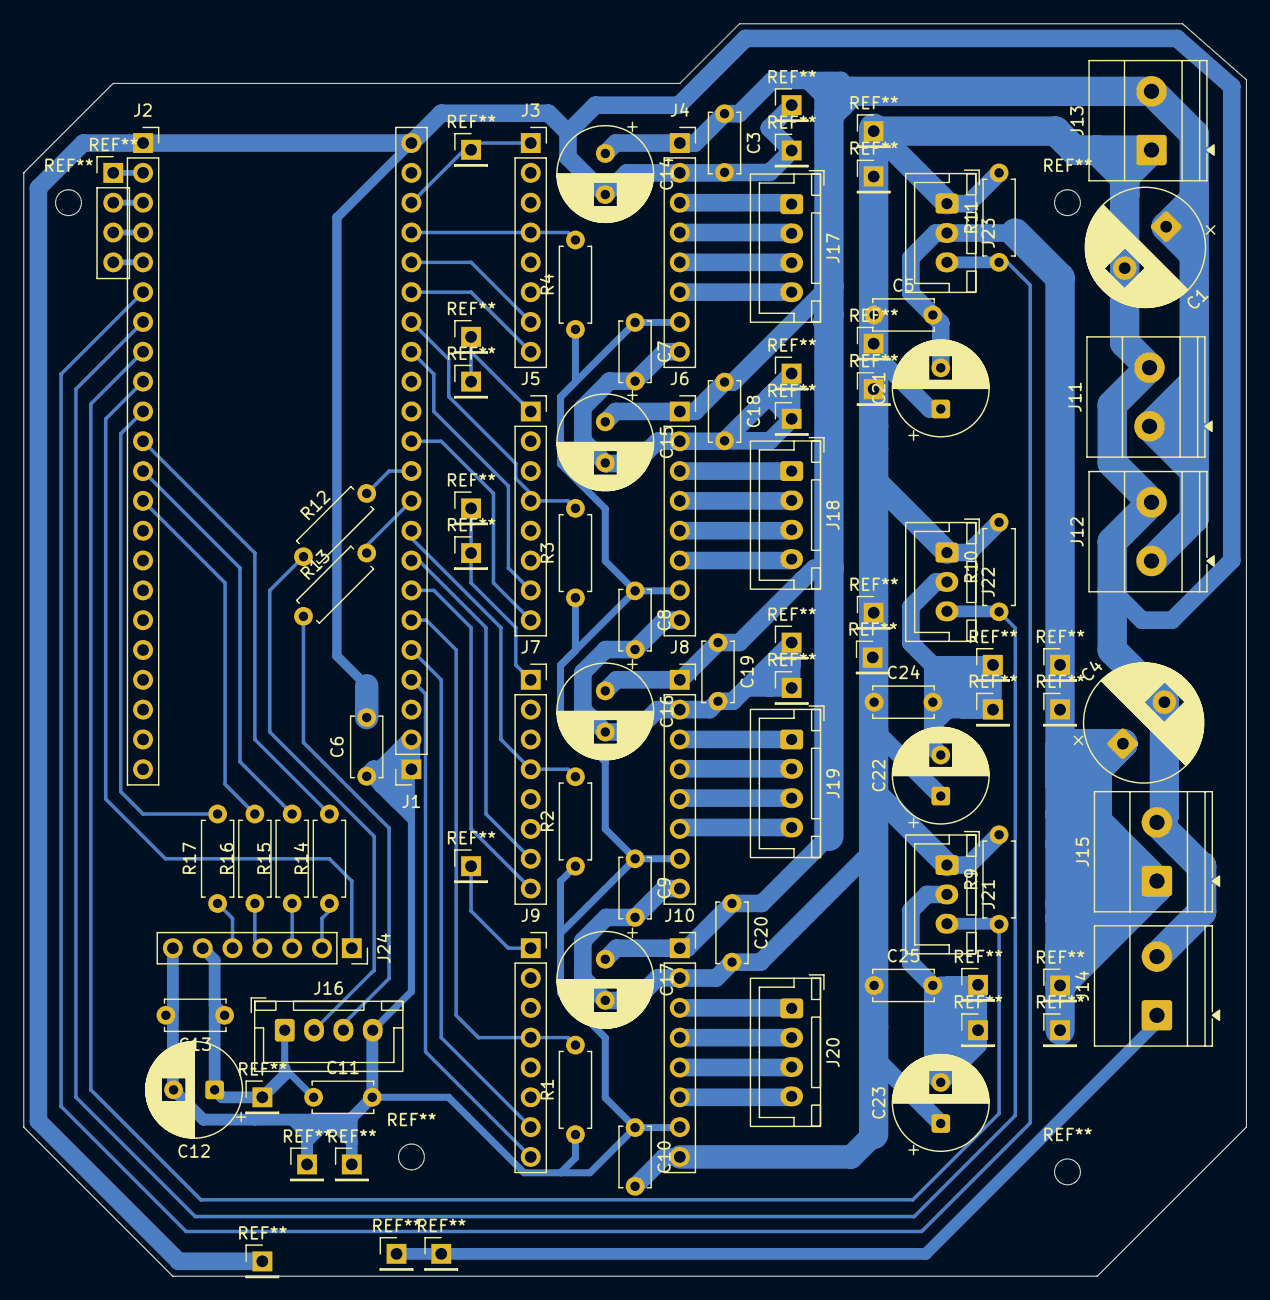
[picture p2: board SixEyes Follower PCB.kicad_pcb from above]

Board: 2 copper layers, 104.1 x 106.7 mm, 61 parts (0 on the bottom side), 43 nets.

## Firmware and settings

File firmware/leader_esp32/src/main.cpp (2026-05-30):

// Leader ESP32-C6 SuperMini teleoperation streamer
// Role: sample leader-arm joint inputs and publish JOINT_STATE at 100 Hz.

#include <Arduino.h>
#include <ArduinoJson.h>
#include <array>
#include <cstring>

namespace {
constexpr uint32_t BAUD_RATE = 115200;
constexpr uint32_t STREAM_HZ = 100;
constexpr uint32_t STREAM_PERIOD_MS = 1000 / STREAM_HZ;
constexpr size_t NUM_JOINTS = 6;
constexpr uint16_t ADC_MAX = 4095;

// Leader ADC pins for 6 joint channels.
// GPIO5 is intentionally avoided due to board-specific ADC instability.
constexpr uint8_t JOINT_ADC_PINS[NUM_JOINTS] = {0, 1, 2, 3, 4, 6};
constexpr const char *CMD_CAPTURE_ZERO = "CAPTURE_ZERO";
constexpr const char *CMD_HOME_ZERO = "HOME_ZERO";

uint32_t sequence = 0;
uint32_t last_stream_ms = 0;
std::array<float, NUM_JOINTS> zero_offsets_deg = {0, 0, 0, 0, 0, 0};
bool zero_captured = false;

float applyZeroOffset(float raw_deg, float zero_deg) {
  float relative_deg = raw_deg - zero_deg;
  if (relative_deg < -180.0f)
    relative_deg = -180.0f;
  if (relative_deg > 180.0f)
    relative_deg = 180.0f;
  return relative_deg;
}

float adcToDegrees(uint16_t raw) {
  const float ratio = static_cast<float>(raw) / static_cast<float>(ADC_MAX);
  return ratio * 180.0f;
}

bool readJointDegrees(float out_degrees[NUM_JOINTS], uint8_t out_valid[NUM_JOINTS]) {
  bool all_valid = true;

  for (size_t i = 0; i < NUM_JOINTS; ++i) {
    int32_t accum = 0;
    for (int s = 0; s < 8; ++s) {
      accum += analogRead(JOINT_ADC_PINS[i]);
    }
    const int raw = static_cast<int>(accum / 8);
    if (raw < 0 || raw > ADC_MAX) {
      out_degrees[i] = 0.0f;
      out_valid[i] = 0;
      all_valid = false;
      continue;
    }

    const float raw_deg = adcToDegrees(static_cast<uint16_t>(raw));
    out_degrees[i] = zero_captured ? applyZeroOffset(raw_deg, zero_offsets_deg[i])
                                   : raw_deg;
    out_valid[i] = 1;
  }

  return all_valid;
}

void captureCurrentPoseAsZero() {
  bool any_valid = false;

  for (size_t i = 0; i < NUM_JOINTS; ++i) {
    int32_t accum = 0;
    for (int s = 0; s < 8; ++s) {
      accum += analogRead(JOINT_ADC_PINS[i]);
    }
    const int raw = static_cast<int>(accum / 8);
    if (raw < 0 || raw > ADC_MAX) {
      continue;
    }

    zero_offsets_deg[i] = adcToDegrees(static_cast<uint16_t>(raw));
    any_valid = true;
  }

  if (any_valid) {
    zero_captured = true;
    Serial.println("[CAL] Leader pot zero captured from current pose");
  } else {
    Serial.println("[CAL] Leader pot zero capture failed (no valid ADC reads)");
  }
}

void handleSerialCommand(const char *line) {
  if (!line || line[0] == '\0') {
    return;
  }

  if (strcmp(line, CMD_CAPTURE_ZERO) == 0 || strcmp(line, CMD_HOME_ZERO) == 0) {
    captureCurrentPoseAsZero();
    return;
  }

  if (line[0] == '{') {
    JsonDocument cmd_doc;
    const DeserializationError err = deserializeJson(cmd_doc, line);
    if (!err && cmd_doc["cmd"].is<const char *>()) {
      const char *cmd = cmd_doc["cmd"].as<const char *>();
      if (strcmp(cmd, CMD_CAPTURE_ZERO) == 0 || strcmp(cmd, CMD_HOME_ZERO) == 0) {
        captureCurrentPoseAsZero();
      }
    }
  }
}

void pollSerialCommands() {
  static char line_buf[128] = {};
  static size_t line_len = 0;

  while (Serial.available() > 0) {
    const int incoming = Serial.read();
    if (incoming < 0) {
      continue;
    }

    const char ch = static_cast<char>(incoming);
    if (ch == '\r') {
      continue;
    }

    if (ch == '\n') {
      line_buf[line_len] = '\0';
      handleSerialCommand(line_buf);
      line_len = 0;
      continue;
    }

    if (line_len < (sizeof(line_buf) - 1)) {
      line_buf[line_len++] = ch;
    } else {
      line_len = 0;
    }
  }
}

void publishJointState() {
  if (!zero_captured) {
    static uint32_t last_remind_ms = 0;
    if ((millis() - last_remind_ms) >= 2000) {
      Serial.println("[WAIT] Send CAPTURE_ZERO or HOME_ZERO to begin streaming");
      last_remind_ms = millis();
    }
    return;
  }

  float joint_degrees[NUM_JOINTS] = {};
  uint8_t valid_mask[NUM_JOINTS] = {};
  readJointDegrees(joint_degrees, valid_mask);

  JsonDocument doc;
  doc["cmd"] = "JOINT_STATE";
  doc["seq"] = sequence;
  doc["ts"] = millis();

  JsonArray joints = doc["leader_joints"].to<JsonArray>();
  JsonArray valid = doc["valid_mask"].to<JsonArray>();

  for (size_t i = 0; i < NUM_JOINTS; ++i) {
    joints.add(joint_degrees[i]);
    valid.add(valid_mask[i]);
  }

  sequence++;
  serializeJson(doc, Serial);
  Serial.println();
}
} // namespace

void setup() {
  Serial.begin(BAUD_RATE);
  delay(100);

  analogReadResolution(12);
  analogSetAttenuation(ADC_11db);

  for (size_t i = 0; i < NUM_JOINTS; ++i) {
    pinMode(JOINT_ADC_PINS[i], INPUT);
  }

  Serial.println("SixEyes leader_esp32 (ESP32-C6 SuperMini) starting (teleoperation mode)");
  Serial.println("Streaming JOINT_STATE at 100 Hz");
  Serial.println("Send HOME_ZERO or CAPTURE_ZERO to latch current pot pose");
}

void loop() {
  pollSerialCommands();

  const uint32_t now = millis();
  if ((now - last_stream_ms) >= STREAM_PERIOD_MS) {
    last_stream_ms = now;
    publishJointState();
  }
}

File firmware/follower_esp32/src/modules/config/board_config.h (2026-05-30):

// Board and system configuration constants
#pragma once

// Safety defaults
static constexpr unsigned long SAFETY_HEARTBEAT_TIMEOUT_MS =
    500; // default ~500 ms

// Control loop frequency (Hz) - choose between 200 and 500
static constexpr int CONTROL_LOOP_HZ = 500;

// Motor/driver counts
static constexpr int NUM_STEPPERS = 4;
static constexpr int NUM_SERVOS = 3;

// Leader-Follower dedicated UART pins (Follower side)
// Per "SixEyes Technical Reference 2":
//   RX (Leader TX) -> GPIO18
//   TX (Leader RX) -> GPIO17
static constexpr int LEADER_UART_RX_PIN = 18;
static constexpr int LEADER_UART_TX_PIN = 17;

// SD SPI + card-detect pins (Follower side)
static constexpr int SD_MOSI_PIN = 35;
static constexpr int SD_SCK_PIN = 36;
static constexpr int SD_MISO_PIN = 37;
static constexpr int SD_CS_PIN = 38;
static constexpr int SD_CD_PIN = 39;

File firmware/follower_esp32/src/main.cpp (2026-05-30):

// SixEyes follower ESP32 - deterministic control loop wiring modules
// Responsibilities: initialize modules and run deterministic control loop at
// CONTROL_LOOP_HZ Dual-mode firmware: VLA Inference (AI task) or Teleoperation
// (real-time mirroring)

#include "modules/comms/message_router.h" // Mode-aware message routing
#include "modules/comms/uart_leader/uart_leader.h"
#include "modules/comms/usb_cdc/usb_cdc.h" // update() called in loop()
#include "modules/config/board_config.h"
#include "modules/config/mode_config.h" // Operation mode selection
#include "modules/drivers/tmc2209/tmc2209_driver.h"
#include "modules/hal/gpio.h"
#include "modules/motor_control/motor_control_scheduler.h"
#include "modules/motor_control/motor_controller.h"
#include "modules/safety/fault_manager.h"
#include "modules/safety/heartbeat_monitor.h"
#include "modules/safety/safety_task.h"
#include "modules/servo_control/servo_manager.h"
#include "modules/telemetry/telemetry_formatter.h"
#include "modules/util/logging.h"
#include <Arduino.h>
#include <array>

void setup() {
  Serial.begin(115200);
  delay(100);
  Logging::info("SixEyes follower_esp32 starting");
  Logging::infof("Operation mode: %s", MODE_NAME());

  HAL_GPIO::init(); // ensures motors disabled by default

  // Initialize drivers and modules (shared by all modes)
  TMC2209Driver::instance().init();
  MotorController::instance().init();
  ServoManager::instance().init();
  TelemetryFormatter::instance().init();
  UartLeader::instance().init(115200);

  // Initialize message router (mode-aware)
  MessageRouter::init();

  // Initialize safety subsystem with ROS2 heartbeat bridge
  // Pass Serial (USB CDC) for ROS2 heartbeat communication
  SafetyTask::instance().init(&Serial);
  FaultManager::instance().init();

  // Start the FreeRTOS control loop (400 Hz, core 0)
  // This runs all control tasks deterministically:
  // SafetyTask → MotorController → ServoManager → HeartbeatMonitor
  MotorControlScheduler::instance().init();
  MotorControlScheduler::instance().start();

  Logging::info("Initialization complete; control loop running on FreeRTOS");
}

void loop() {
  // USB CDC: check host connect/disconnect state (100 ms poll is sufficient)
  UsbCDC::instance().update();
  // Main FreeRTOS control loop runs on core 0 at CONTROL_LOOP_HZ
  delay(100);
}

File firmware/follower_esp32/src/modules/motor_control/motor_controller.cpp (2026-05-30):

#include "motor_controller.h"
#include "modules/drivers/tmc2209/tmc2209_driver.h"
#include <Arduino.h>
#include <algorithm>
#include <cmath>
#include <esp_rom_sys.h>

namespace {
constexpr float kDegreesPerStep =
    360.0f / (TMC2209_FULL_STEPS_PER_REV * TMC2209_MICROSTEPS);
constexpr int8_t kHomingDirectionSign[NUM_STEPPERS] = {
    -1, // Base
    -1, // Shoulder A
    1,  // Shoulder B (mirrored)
    -1  // Elbow
};

inline float signf_nonzero(float v) { return (v >= 0.0f) ? 1.0f : -1.0f; }
} // namespace

MotorController &MotorController::instance() {
  static MotorController inst;
  return inst;
}

MotorController::MotorController() {
  current_positions_.fill(0.0f);
  current_velocities_.fill(0.0f);
  target_positions_.fill(0.0f);
  position_errors_.fill(0.0f);
  current_steps_.fill(0);
  target_steps_.fill(0);
  zero_offsets_steps_.fill(0);
  homing_latched_zero_steps_.fill(0);
  planner_velocity_steps_s_.fill(0.0f);
  planner_accel_steps_s2_.fill(0.0f);
}

void MotorController::stepTimerCallback(void *arg) {
  auto *self = static_cast<MotorController *>(arg);
  if (!self) {
    return;
  }

  if (!self->enabled_ || self->homing_phase_ != HomingPhase::IDLE) {
    return;
  }

  int32_t emit_counts[NUM_STEPPERS] = {0};
  bool emit_direction_positive[NUM_STEPPERS] = {false};

  portENTER_CRITICAL(&self->motion_lock_);
  for (size_t motor_index = 0; motor_index < NUM_STEPPERS; ++motor_index) {
    const float rate_steps_s = self->commanded_step_rate_steps_s_[motor_index];
    const float abs_rate = std::abs(rate_steps_s);

    if (abs_rate < 0.001f) {
      continue;
    }

    float phase = self->step_phase_accumulator_[motor_index];
    phase += abs_rate * (static_cast<float>(STEP_TIMER_PERIOD_US) / 1000000.0f);

    int32_t emit = static_cast<int32_t>(phase);
    if (emit > 0) {
      phase -= static_cast<float>(emit);
      emit_counts[motor_index] = emit;
      emit_direction_positive[motor_index] = rate_steps_s > 0.0f;
      self->step_position_isr_[motor_index] +=
          emit_direction_positive[motor_index] ? emit : -emit;
    }

    self->step_phase_accumulator_[motor_index] = phase;
  }
  portEXIT_CRITICAL(&self->motion_lock_);

  for (size_t motor_index = 0; motor_index < NUM_STEPPERS; ++motor_index) {
    const int32_t emit = emit_counts[motor_index];
    if (emit <= 0) {
      continue;
    }

    digitalWrite(TMC2209_DIR_PINS[motor_index],
                 emit_direction_positive[motor_index] ? HIGH : LOW);
    for (int32_t step = 0; step < emit; ++step) {
      digitalWrite(TMC2209_STEP_PINS[motor_index], HIGH);
      esp_rom_delay_us(STEP_PULSE_HIGH_US);
      digitalWrite(TMC2209_STEP_PINS[motor_index], LOW);
      esp_rom_delay_us(STEP_PULSE_LOW_US);
    }
  }
}

void MotorController::initStepTimer() {
  if (step_timer_) {
    return;
  }

  esp_timer_create_args_t timer_args = {};
  timer_args.callback = &MotorController::stepTimerCallback;
  timer_args.arg = this;
  timer_args.dispatch_method = ESP_TIMER_ISR;
  timer_args.name = "step_gen";

  if (esp_timer_create(&timer_args, &step_timer_) != ESP_OK) {
    Serial.println("MotorController: failed to create step timer");
    step_timer_ = nullptr;
    return;
  }

  if (esp_timer_start_periodic(step_timer_, STEP_TIMER_PERIOD_US) != ESP_OK) {
    Serial.println("MotorController: failed to start step timer");
    esp_timer_delete(step_timer_);
    step_timer_ = nullptr;
    return;
  }

  Serial.print("MotorController: step timer started @ ");
  Serial.print(STEP_TIMER_PERIOD_US);
  Serial.println(" us");
}

void MotorController::setCommandedStepRate(uint8_t motor_index,
                                           float steps_per_s) {
  const float max_step_rate = MAX_MOTOR_SPEED_DEG_PER_S / kDegreesPerStep;
  const float clamped =
      std::max(-max_step_rate, std::min(max_step_rate, steps_per_s));

  portENTER_CRITICAL(&motion_lock_);
  commanded_step_rate_steps_s_[motor_index] = clamped;
  portEXIT_CRITICAL(&motion_lock_);
}

void MotorController::setAllCommandedRatesToZero() {
  portENTER_CRITICAL(&motion_lock_);
  for (size_t i = 0; i < NUM_STEPPERS; ++i) {
    commanded_step_rate_steps_s_[i] = 0.0f;
    step_phase_accumulator_[i] = 0.0f;
  }
  portEXIT_CRITICAL(&motion_lock_);
}

void MotorController::syncIsrStepPositionFromCurrent() {
  portENTER_CRITICAL(&motion_lock_);
  for (size_t i = 0; i < NUM_STEPPERS; ++i) {
    step_position_isr_[i] = current_steps_[i];
  }
  portEXIT_CRITICAL(&motion_lock_);
}

void MotorController::init() {
  setupStepPins();
  initStepTimer();
  syncIsrStepPositionFromCurrent();

  Serial.println("MotorController: init timer-driven planner + step generator "
                 "(open-loop)");
  Serial.print("  - Deg/step: ");
  Serial.println(kDegreesPerStep, 6);
  Serial.print("  - Max speed (deg/s): ");
  Serial.println(MAX_MOTOR_SPEED_DEG_PER_S, 1);
  Serial.print("  - Max accel (deg/s^2): ");
  Serial.println(MAX_MOTOR_ACCEL_DEG_PER_S2, 1);
  Serial.print("  - Max jerk (deg/s^3): ");
  Serial.println(MAX_MOTOR_JERK_DEG_PER_S3, 1);
}

void MotorController::enforceShoulderAntiPhaseLock() {
  constexpr size_t SHOULDER_A = 1;
  constexpr size_t SHOULDER_B = 2;

  const int32_t shoulder_a_relative_steps =
      target_steps_[SHOULDER_A] - zero_offsets_steps_[SHOULDER_A];
  target_steps_[SHOULDER_B] =
      zero_offsets_steps_[SHOULDER_B] - shoulder_a_relative_steps;
  target_positions_[SHOULDER_B] = stepsToDegrees(
      target_steps_[SHOULDER_B] - zero_offsets_steps_[SHOULDER_B]);
}

void MotorController::setAbsoluteTargets(
    const std::array<float, NUM_STEPPERS> &targets) {
  if (homing_phase_ != HomingPhase::IDLE &&
      homing_phase_ != HomingPhase::COMPLETE) {
    return;
  }

  for (int i = 0; i < NUM_STEPPERS; ++i) {
    target_positions_[i] = targets[i];
    target_steps_[i] =
        zero_offsets_steps_[i] + degreesToSteps(target_positions_[i]);
  }

  enforceShoulderAntiPhaseLock();

  for (int i = 0; i < NUM_STEPPERS; ++i) {
    position_errors_[i] = target_positions_[i] - current_positions_[i];
  }
}

float MotorController::stepsToDegrees(int32_t steps) {
  return static_cast<float>(steps) * kDegreesPerStep;
}

int32_t MotorController::degreesToSteps(float degrees) {
  const float steps_f = degrees / kDegreesPerStep;
  return static_cast<int32_t>(lroundf(steps_f));
}

void MotorController::setupStepPins() {
  for (size_t i = 0; i < NUM_STEPPERS; ++i) {
    pinMode(TMC2209_STEP_PINS[i], OUTPUT);
    pinMode(TMC2209_DIR_PINS[i], OUTPUT);
    digitalWrite(TMC2209_STEP_PINS[i], LOW);
    digitalWrite(TMC2209_DIR_PINS[i], LOW);
  }
}

void MotorController::pulseStepPin(uint8_t motor_index) {
  digitalWrite(TMC2209_STEP_PINS[motor_index], HIGH);
  delayMicroseconds(STEP_PULSE_HIGH_US);
  digitalWrite(TMC2209_STEP_PINS[motor_index], LOW);
  delayMicroseconds(STEP_PULSE_LOW_US);
}

bool MotorController::isMotorSelectedForHoming(uint8_t motor_index) const {
  return ((homing_mask_ >> motor_index) & 0x01) != 0;
}
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

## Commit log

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2026-05-21 hardware: remap TMC2209 to 6-wire JST pinout
    [SixEyes Follower PCB.kicad_pcb, SixEyes Follower PCB.kicad_sch]
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2026-05-30 refactor: flatten sixeyes/ to root, add KiCad PCB project, fix JSON pipeline, fix safety bitmask, implement ROS2 nodes, update docs
    - Flatten sixeyes/ wrapper: firmware/, ros2_ws/, tools/, simulation/, hardware_assets/ now at repo root
    - Merge sixeyes/docs/ into docs/ (safety.md, protocols/uart_protocol.md)
    - Add KiCad follower PCB project files (.kicad_pro, .kicad_prl, fp-lib-table, custom footprints, design_inputs/)
    - Update .gitignore: exclude KiCad .history/ and *-backups/ directories
    - Fix UartJsonParser pipeline: init() now called in MessageRouter::init(), update() ticked each control loop iteration
    - Add JOINT_STATE (type 8) to MessageType enum, parse block, struct, and TeleoperationH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
    [SixEyes Follower PCB.kicad_pcb, SixEyes Follower PCB.kicad_sch, follower_nodemesh_footprint_map.csv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]
2026-05-30 fix: resolve P0/P1/P2 deployment blockers
    P0 - ROS2 launch files:
    - Add sixeyes_bringup package with teleop.launch.py (4 nodes) and vla.launch.py (5 nodes)
    - Operators can now start the entire system with one command
    P0 - VLACommandHandler::handleCommand():
    - Now validates against known VLA command names; returns false for unknown commands
    - Explicit MODE_CHANGE rejection with helpful recompile message
    - No longer returns true unconditionally
    P1 - TeleoperationHandler::handleCommand() dead code:
    - Remove the 120-line handleCommand() implementation (UartJsonParser callbacks are the real entry point)
    - Remove dead handleJointState() helper it called
    - Remove now-unused tmc2209_driver.h inclu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
    [message_router.cpp, motor_control_scheduler.cpp, teleoperation_handler.cpp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]
2026-06-08 Alpha/Beta development, June 2026
    Combines the work from 4 to 8 June 2026: restructuring the firmware into Alpha and Beta
    variants, the Beta follower and leader PCB design packages and KiCad parts, the technical
    reference and documentation rewrite, the CERN-OHL-S hardware licence, open-loop stepper
    mitigation strategies for the Beta firmware, and the project credits.
2026-10-17 Move Alpha/Beta to legacy/, add v1 CAN protocol draft and TODO
    Alpha and Beta firmware, PCB projects, and docs relocated under
    legacy/ ahead of the v1 Universal Joint PCB rework (no leader arm,
    distributed CAN nodes). Deleted stale duplicate technical-reference
    files, repaired all internal doc links, and drafted the CAN message
    protocol and safety model that firmware/v1 will implement against.
2026-10-17 v1.2 hardware redesign: through-hole spec, LCSC BOM, firmware pin map, doc updates
    Super Mini + XL4016/LM2940 + MCP2562 + AS5600 design reference and BOM; NEMA17 torque budget; v1 firmware updated (pin map, single-wire TMC2209 + EN, AS5600 I2C driver, E-stop drops EN).
2026-10-17 hardware: update v1.2 BOM and PCB reference
    - Motor connector JDR3 is now the right-angle JST S4B-XH-A (LCSC C157925)
    - Add M3x8 brass female-female standoffs (LCSC C551328) that carry the motor
    - AS5600 module is soldered directly to the PCB (no sockets), with slotted holes
    for the 13.5 mm row spacing; remove its socket rows from the BOM
    - Document motor mounting: 8 mm standoff + 1.5 mm indentation, M3x14 screw with a
    0.5 mm washer, 2.5 mm shaft-to-IC gap
    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
2026-10-17 Remove legacy Alpha/Beta material from main
    The ESP32-S3 Alpha/Beta firmware, their KiCad projects, legacy docs, the superseded
    v1.1 PCB reference and the June 2026 technical reference are no longer needed to build
    the v1 arm. All of it stays on the archive/dev-2026-10 branch and the
    pre-cleanup-2026-10 tag.
2026-10-17 Remove ROS2 workspace and legacy teleoperation tools
    ROS2 and the leader-arm teleoperation scripts are out of scope for the hardware release.
    They remain on the archive/dev-2026-10 branch and the pre-cleanup-2026-10 tag.
2026-10-17 hardware: add KiCad v1.2 project, SixEyes_custom library and generator scripts
    - KiCad project for the v1.2 Universal Joint PCB, with the source 3D models used
    for the custom parts ("Custom Assets")
    - SixEyes_custom library: AS5600 module footprint (slotted holes, 13.5 mm rows),
    NEMA17 mechanical part, M3x8 brass standoff; unused AS5600 model variants are
    kept in custom_lib/_archive
    - tools/add_custom_parts.py regenerates the library; tools/make_standoff_step.py
    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
2026-10-17 Reorganise repository layout
    Rename hardware_assets to hardware (pcb/kicad, pcb/libraries, pcb/bom, pcb/gerbers,
    mechanical/stl, tools), firmware/v1/joint_node to firmware/joint_node, and gather the
    reference documents under docs/reference. Pure moves; paths inside files are fixed in
    the following commits.
2026-10-17 Add the LCSC parts used by the board
    Symbols, footprints and 3D models for the 23 parts the board uses (converted from the
    EasyEDA/LCSC library with easyeda2kicad), so the KiCad project opens without extra setup.
    STEP copies are included only for footprints placed on the board. A README notes where
    they come from and that third-party model licences are unverified.
2026-10-17 Use project-relative library and 3D-model paths
    The KiCad library tables and the PCB's 3D-model paths pointed at a private absolute path;
    they now resolve relative to the project (${KIPRJMOD}). The generator scripts use the new
    hardware/ layout.
2026-10-17 Update cross-references after the reorganisation
    Fix document links and the library paragraph in the PCB reference, point firmware comments
    at docs/reference, drop references to files that moved to the archive branch, and update
    the scope paths in the hardware licence notice.
2026-10-17 Remove the unmaintained code-quality workflow
    It pointed at a firmware folder that no longer exists. A build check for
    firmware/joint_node comes with the CI update.
2026-10-17 Rewrite README and CONTRIBUTING for people building the arm
    The README now explains what you build, where to start, the repository layout, current
    status and the three licences. CONTRIBUTING covers the licences for firmware, hardware and
    documentation, with the new paths. Remove the unused ROS2 ignore rules.
2026-10-17 Update CI for the v1 firmware and pin the ESP32 platform
    Build all four joint-board roles on every firmware change, and replace the release
    workflow with one that publishes the firmware binaries, the bill of materials and
    checksums for a version tag. The ESP32-C6 needs Arduino core 3.x, which PlatformIO's
    official espressif32 platform does not ship, so pin the pioarduino platform release the
    firmware was built with.
2026-10-20 Update the joint board for UART mode and the new pin map
    MS1 and MS2 move to GPIO15 and GPIO16, UART TX to GPIO5, and the module's VREF
    pad is read on GPIO2 through a new 10k resistor (R5). Adds the JDR4 socket for
    the module's VREF and DIAG pads, VM and EN markers, a corrected regulator label,
    JLCPCB 4-layer stackup and limits, net classes, and custom design rules for
    power track widths, via sizes and the CAN pair. BOM gains the second 10k
    resistor and JDR4.
2026-10-20 Add a script that runs KiCad DRC and summarises it
    Runs kicad-cli on a copy of the project, de-duplicates the report and lists
    shorts, open nets, near-shorts and custom-rule violations first.
2026-10-20 Update the joint firmware for the new pins and UART mode
    New pin map for MS1, MS2, UART TX and the VREF ADC. At boot the driver probes
    UART at address 0. If it answers, the firmware forces digital current and
    starts at 500 mA RMS. If not, it warns, releases the UART pins and falls back to
    STEP/DIR with the MS pins and a VREF check before enabling the driver.
2026-10-20 Add TMC2209 module notes, schematics and IC pin verification
    Side-by-side comparison of the two supported driver modules with their
    schematic PDFs, a log of what was tested and learned about UART, and a record
    of how each IC's pins were checked against its datasheet.
2026-10-20 Write the build, flash and assemble guides and update the docs
    Build guide with safety rules, soldering order, double-checks and driver module
    setup. Draft flash and assemble guides, a note to reviewers about the tight
    placement, the assembly render, and updated design reference and READMEs.
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2026-10-22 Update fabrication files and drawings for the terminal pinout silkscreen; add board renders to the docs
    Regenerated Gerber zip (new checksum), re-signed layout PDF, bare-board and assembly renders in the guides and READMEs, budget scope now excludes shipping, PCB quote added.
2026-10-26 Rework the budget around a price survey; add the power budget; use the rear shaft end of single-shaft motors for the magnet
    Budget now shows low, average and high prices from a dated AliExpress price survey (price-survey.csv) with listing links. New draft power and current budget. Docs no longer require dual-shaft motors.
2026-10-26 Add the arm bill of materials; bring the guides and index up to date; add the fuse to the budget
    New hardware/bom/arm_BOM.csv and a BOM table in the parts guide, guide status labels and overview refreshed, 7.5 A blade fuse priced, power budget updated.
2026-10-27 Add the host protocol link, joint model and node telemetry to the firmware
    The Base board now speaks the SixEyes host protocol v1 over USB (COBS + CRC-16 framing, hello, acks, control-source and watchdog rules, 50 Hz state stream). Adds the joint model (encoder on the motor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
2026-10-27 Add step generation, motion control, sensorless homing and a bench console
    STEP pulses from a hardware timer with a trapezoid move and encoder settle trim; homing drives each stepper into its stop (StallGuard polled over UART plus an encoder check); a v1_bench build to move and tune one motor. Fixes the StallGuard helpers, which read the wrong registers, and gates motor enabling on the safety task. Part 2 of 4; homing stop angles and thresholds are placeholders and nothing has run on hardware.
2026-10-27 Add the Bluetooth link and the BOOT-button stop
    NimBLE GATT transport for the host protocol with a bonded, encrypted link and a pairing window (60 s after power-up, or a 3 s hold of BOOT on Base). The BOOT button on any board stops the whole arm. 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
2026-10-27 Add motion slots: save motions on the arm and play them back
    Four slots in the LittleFS flash filesystem, written sample by sample and replayed with a slow approach to the first pose. Part 4 of 4; not tested on hardware.
2026-10-27 Document the firmware work: host link, homing, Bluetooth, stop button and motion slots
    Firmware README (what is real, bench test, homing checklist, Bluetooth and motion slots), CAN protocol notes, flashing and assembly guide status.
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2026-11-07 Update build guide: new solder order, two diagonal standoffs, 47 uF CDR1
    Solder order: inductor, back small parts and encoder header pins, front small
    parts, buck/LDO/catch diode, electrolytics, sockets and terminals, encoder
    module last (bought with header pins unsoldered).
    Motor mount: two diagonal M3x8 standoffs (SO2, SO4); through-screw length TBD.
    CDR1: 100 uF replaced by a proposed 47 uF 50 V (C45100, unconfirmed) because
    the tall part hit the TMC2209. First v1.2 board marked as built.
    Use not-for-profit in the README.
